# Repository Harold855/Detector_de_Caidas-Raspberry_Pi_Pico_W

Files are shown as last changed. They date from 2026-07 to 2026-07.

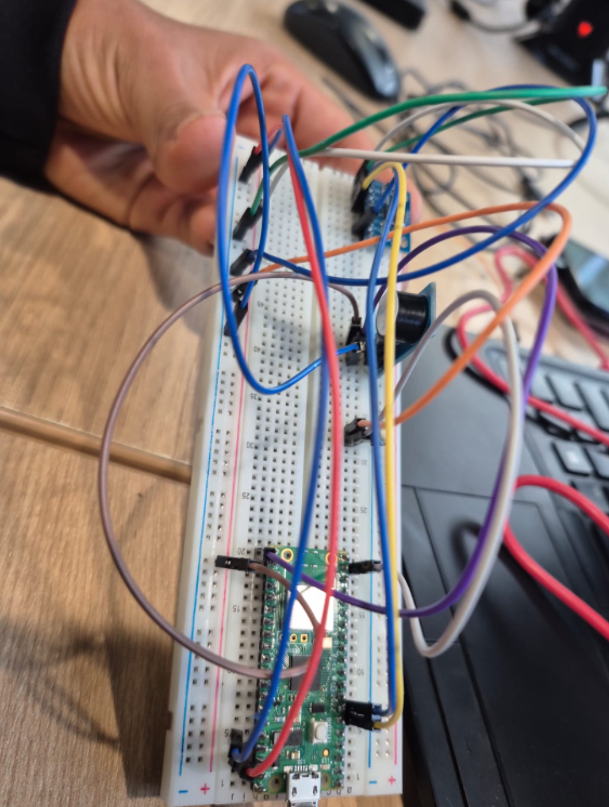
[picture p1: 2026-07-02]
evidencias/Avance Presencial/Evidencia_Avance_2.png

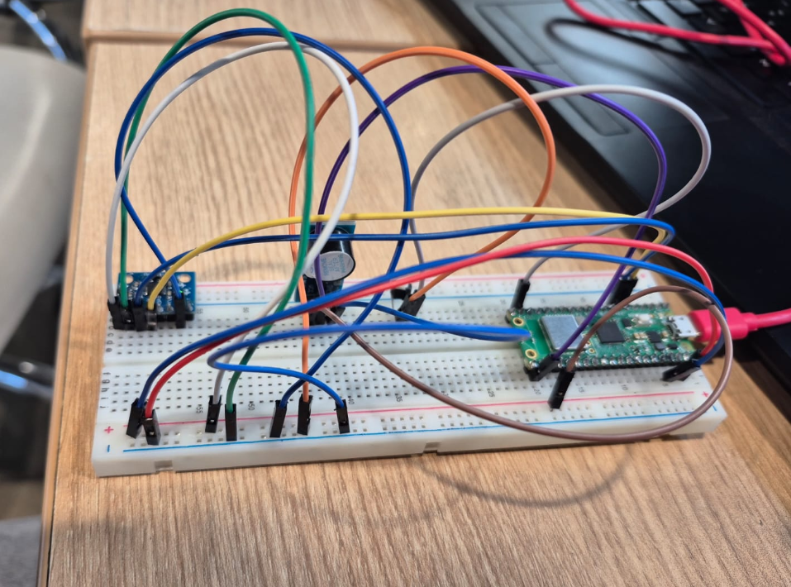
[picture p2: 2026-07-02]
evidencias/Avance Presencial/Evidencia_Avance_1.png

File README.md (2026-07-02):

# Sistema IoT de Detección de Caídas para Adultos Mayores

## Descripción

Este proyecto consiste en la implementación de un sistema con microcontrolador, codificado en MicroPython, en un dispositivo portátil. Este sistema usa una Raspberry Pi Pico W, un sensor MPU6050, ,un buzzer, un botón de cancelación y un bot de Telegram para enviar alertas a un grupo familiar.

## Razón de Creación o Problema Principal

Las caídas en adultos mayores pueden ocurrir cuando la persona se encuentra sola o sin supervisión. Y en algunos casos, la persona puede tener dificultad para levantarse o incluso pueden quedar incapaces de pedir ayuda. Por ello, este sistema busca alertar rápidamente, mediante un mensaje a los familiares en un grupo de Telegram, cuando se detecta un movimiento brusco relacionado con una posible caída.

## Usuario objetivo

El sistema está dirigido principalmente a adultos mayores que normalmente permanecen solos en casa. También beneficia a familiares o cuidadores, ya que les permite recibir alertas mediante Telegram.

## Componentes usados

|**Componente**|**Función**|
|-|-|
|Microcontrolador Raspberry Pi Pico W|Controla el sistema y se conecta a interne|
|Módulo IMU MPU6050|Detecta aceleración, giro e inclinación |
|Buzzer/Zumbador|Emite la alarma sonora|
|Botón pulsador|Cancela falsas alarmas o silencia la alarma|
|Powerbank|Alimenta el sistema|
|Carcasa impresa en 3D|Protege los componentes y permite colocarlo en una correa|

## Funcionamiento

El sistema lee constantemente los valores del MPU6050. La detección no se basa solo con un golpe o movimiento brusco. Primero, el sistema revisa si hubo un giro fuerte acompañado de movimiento. Luego, durante unos segundos, verifica si la persona quedó en una postura anormal y con poca movilidad.
Si estas condiciones se cumplen, el sistema interpreta que puede tratarse de una posible caída. En ese momento, el buzzer emite una alarma y el bot de Telegram envía un mensaje de posible caída al grupo familiar.
Después, el sistema espera 5 segundos para que la persona pueda cancelar la alerta con un toque en el botón. Si presiona el botón, se envía un mensaje de falsa alarma. Si no lo presiona, el sistema confirma la emergencia y envía un mensaje urgente al grupo familiar.
Además, el programa revisa periódicamente la conexión Wi-Fi. Si se desconecta, intenta reconectarse. También incluye un pequeño pulso del buzzer para evitar que algunos powerbanks se apaguen automáticamente por bajo consumo.

## Mensajes de Telegram

El bot puede enviar los siguientes mensajes:

* Dispositivo conectado y listo
* Posible caída detectada
* Falsa alarma cancelada
* Caída confirmada
* Alarma silenciada

## Cómo puedes ejecutar el proyecto

Si deseas ejecutar el proyecto por tu cuenta, debes seguir estos 7 pasos:

1. Instalar MicroPython en la Raspberry Pi Pico W
2. Abrir Thonny
3. Copiar el código en la Pico W
4. Guardar el archivo como "main.py"
5. Conectar el circuito según el diagrama
6. Conectar la Pico W a una laptop o powerbank
7. Verificar que el bot envíe mensajes al grupo de Telegram

## Seguridad de credenciales

Por seguridad, no se deben subir al repositorio los datos reales de Wi-Fi ni el token del bot de Telegram. Por lo que, el archivo con los datos reales solo debe usarse en la Raspberry Pi Pico W.

WIFI_NOMBRE = "COLOCA AQUI EL NOMBRE DE TU WIFI"
WIFI_CLAVE = "COLOCA AQUI LA CLAVE TU WIFI"
TELEGRAM_TOKEN = "COLOCA AQUI EL TOKEN GENERADO POR TU BOT"
TELEGRAM_CHAT_ID = "COLOCA AQUI TU ID DEL CHAT"

## Diagrama de conexiones

|Componente|Pin en Raspberry Pi Pico W|
|-|-|
|MPU6050 SDA|GP4|
|MPU6050 SCL|GP5|
|MPU6050 VCC|3V3|
|MPU6050 GND|GND|
|Botón Pulsador|GP14 y GND|
|Buzzer|GP16, 3V3 y GND|
|Powerbank|Puerto Micro USB de la Pi Pico W|

## Diagrama de flujo del sistema

```mermaid
flowchart TD 
   A[Inicio] --> B[Conectar Wi-Fi]
   B --> C[Leer sensor MPU6050]
   C --> D{¿Detecta posible caída?}
   
   D -- No --> C
   D -- Sí --> E[Activar buzzer]
   E --> F[Enviar aviso a Telegram]
   F --> G{¿Presionó el botón en 5 segundos?}

   G -- Sí --> H[Cancelar alerta]
   H --> I[Enviar falsa alarma a Telegram]
   I --> C

   G -- No --> J[Confirmar emergencia]
   J --> K[Enviar caída confirmada a Telegram]
   K --> L[Sonar alarma]
   L --> M{¿Alguien silencia la alarma?}
   
   M -- Sí --> N[Enviar alarma silenciada]
   N --> C

   M -- No --> L

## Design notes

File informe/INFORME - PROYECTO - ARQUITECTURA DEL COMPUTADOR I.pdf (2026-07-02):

FACULTAD DE INGENIERÍA

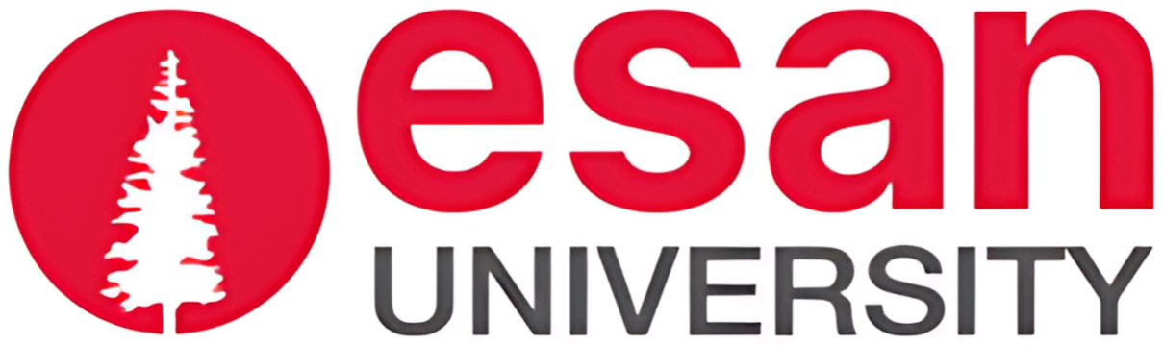
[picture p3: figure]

PROYECTO FINAL - GRUPO 6

Detección de Caídas para Adultos Mayores

CURSO: ARQUITECTURA DEL COMPUTADOR I

SECCIÓN: 001

PROFESOR: MARKS CALDERÓN

INTEGRANTES:

- Jorge Daniel Rivera Nagaro | 23101246
- Rodrigo Sebastián Escobar Rosado | 25100454
- Harold Lincoln Payco Espinoza | 25102426

Lima 2026

Índice

Introducción

Problema Real

Las caídas en adultos mayores son situaciones que pueden ocurrir en cualquier momento,

especialmente cuando la persona se encuentra sola en casa o no cuenta con supervisión

constante. En muchos casos, después de una caída, la persona puede tener dificultad para

levantarse, pedir ayuda o comunicarse rápidamente con sus familiares. Además, esto puede

llegar a ser grave, debido a que una caída puede ocasionar lesiones importantes y poner en

riesgo la salud de la persona afectada . Por ello, es importante contar con una herramienta que

permita avisar de manera oportuna cuando ocurre un movimiento brusco que pueda estar

relacionado con una posible caída.

Usuario Principal

Como se mencionó anteriormente, este dispositivo está enfocado principalmente en adultos

mayores que permanecen solos durante algunas horas del día o que requieren mayor cuidado

por parte de sus familiares. También beneficia a los familiares o cuidadores, ya que les

permite recibir una alerta rápida en caso de que la persona pueda necesitar ayuda.

Objetivo del proyecto

El objetivo del proyecto es desarrollar un dispositivo portátil que pueda colocarse en la

cintura de una persona mayor para detectar movimientos bruscos o cambios repentinos de

posición. Cuando el sistema identifica una posible caída, activa una alarma sonora y envía un

aviso automático a un grupo familiar de Telegram. Además, permite cancelar la alerta

mediante un botón si la persona se encuentra bien.

Alcance del proyecto

El proyecto consiste en un prototipo académico de detección y aviso de posibles caídas. Con

este sistema no busca reemplazar la atención médica ni garantizar la detección exacta de

todas las caídas; más bien, sirve como una herramienta de apoyo para mejorar la

comunicación entre el adulto mayor y sus familiares. Su funcionamiento se basa en la lectura

del movimiento del cuerpo, la activación de una alarma local y el envío de mensajes de alerta

mediante conexión a internet.

Diseño del sistema

Arquitectura del sistema

El sistema fue diseñado como un dispositivo portátil que puede colocarse en la cintura de una

persona mayor. Su funcionamiento inicia cuando el sensor MPU6050 registra los

movimientos del cuerpo. Luego, la Raspberry Pi Pico W analiza esos datos para identificar si

hubo un giro brusco acompañado de movimiento fuerte.

A diferencia de una detección simple, el sistema no confirma una posible caída solo por un

golpe o movimiento repentino. Primero revisa si ocurrió un giro fuerte y luego, observa si,

durante unos segundos, la persona quedó quieta y en una postura anormal. Cuando estas

condiciones se cumplan, el sistema activa el buzzer y envía un aviso al grupo familiar de

Telegram. Además, el sistema permite cancelar la alerta mediante un botón. Si la persona

presiona el botón dentro del tiempo establecido, se informa que fue una falsa alarma. En

cambio, si no se presiona, el sistema confirma la emergencia y envía un mensaje urgente al

grupo familiar.

Componentes del sistema

El sistema está formado por una Raspberry Pi Pico W, un módulo MPU6050, un buzzer, un

botón pulsador, conexión Wi-Fi, un bot de Telegram, una batería recargable o powerbank,

una carcasa impresa en 3D y una correa ajustable. La Raspberry Pi Pico W controla el

funcionamiento del sistema y permite la conexión a internet. El MPU6050 mide la

aceleración, el giro y la inclinación del cuerpo. El buzzer funciona como alarma sonora local.

El botón permite cancelar una falsa alarma o silenciar la emergencia cuando alguien ya se

encuentra con la persona. Finalmente, Telegram permite enviar los mensajes al grupo

familiar.

Funcionamiento de los dos sensores del MPU6050

El módulo MPU6050 integra dos mediciones principales, estas serían: la aceleración y giro.

La aceleración permite identificar movimientos bruscos o golpes, por ejemplo, cuando el

cuerpo cambia de posición de manera repentina. Por otro lado, el giro permite reconocer

rotaciones rápidas o inclinaciones que podrían ocurrir durante una caída. Aparte este tiene un

papel importante, ya que se utiliza como primer filtro para detectar un evento que podría estar

relacionado con una caída. Después de ello, el sistema revisa si la persona quedó en una

posición anormal y con poca movilidad. De esta manera, el dispositivo no depende de un solo

dato, sino que combina movimiento, giro, postura y quietud.

Lógica de detección

La lógica de detección se divide en dos momentos. Primero, el sistema revisa si hubo un giro

brusco acompañado de movimiento. Si no ocurre este evento, el dispositivo continúa leyendo

los datos del sensor sin activar ninguna alerta.

Si el giro brusco sí ocurre, el sistema realiza una segunda verificación. Revisa, durante unos

segundos, si la persona quedó en una postura anormal y con poca movilidad. Si estas

condiciones no se llegan a cumplir, el sistema descarta el evento porque puede tratarse de un

movimiento normal, como girarse rápido, sentarse o mover el dispositivo.

En cambio, si el sistema detecta giro brusco, postura anormal e inmovilidad, se activa el

buzzer y se envía un mensaje de posible caída a Telegram. Luego, la persona tiene 5

segundos para cancelar la alerta con un toque en el botón. Si presiona el botón, se informa

una falsa alarma. Si no lo presiona, el sistema confirma la emergencia y envía un mensaje

urgente al grupo familiar.

Implementación

Conexiones del circuito

Para la construcción del prototipo se utilizó una Raspberry Pi Pico W como unidad principal

del sistema. A esta placa se conectó el módulo MPU6050, encargado de medir los

movimientos del cuerpo. También se conectó un buzzer, que funciona como alarma sonora, y

un botón pulsador, que permite cancelar una falsa alarma o silenciar la alerta cuando alguien

ya se encuentra con la persona.

El MPU6050 se conectó a los pines GP4 y GP5 de la Raspberry Pi Pico W. El botón fue

conectado al pin GP14 y el buzzer al pin GP16. Y para la alimentación, se uso de una batería

recargable o powerbank mediante el puerto micro USB de la placa.

Programación en MicroPython

El código se organizó en varias funciones para facilitar su funcionamiento y explicación. Una

función prepara los componentes principales, la otra conecta el dispositivo al Wi-Fi, otra

envía mensajes a Telegram y otra lee los valores del sensor MPU6050.

Además, el programa incluye mejoras de estabilidad. Por ejemplo, revisando periódicamente

si la conexión Wi-Fi sigue activa y, si se pierde, intenta reconectarse. También realiza

reintentos al enviar mensajes por Telegram, para evitar que una falla momentánea de internet

detenga el aviso. También cuenta con un pequeño pulso del buzzer cada cierto tiempo. Esto

ayuda a evitar que algunos powerbanks se apaguen cuando detectan bajo consumo.

Finalmente, el programa cuenta con una protección que permite reiniciar la Raspberry Pi Pico

W si ocurre un error grave, de modo que el sistema pueda seguir funcionando mientras tenga

energía.

Flujo del programa

El programa inicia preparando el buzzer, el botón, el sensor MPU6050 y la conexión Wi-Fi.

Luego, si la conexión a internet está disponible, envía un mensaje inicial al grupo familiar de

Telegram indicando que el dispositivo está listo. Después, el sistema entra en un ciclo

continuo de lectura. En cada lectura, obtiene información sobre aceleración, giro e

inclinación. Si detecta un giro brusco acompañado de movimiento, no activa la alarma de

inmediato, sino que realiza una verificación adicional. En esta etapa se revisa si la persona

quedó en una postura anormal y con poca movilidad.

Si la verificación confirma una posible caída, el buzzer se activa y el sistema envía un

mensaje de posible caída a Telegram. Luego, la persona tiene 5 segundos para cancelar la

alerta mediante un toque en el botón. Si el botón es presionado, se envía un mensaje de falsa

alarma. Si no es presionado, se confirma la emergencia y se envía un mensaje urgente al

grupo familiar.

Alerta por Telegram

Para el envío de alertas se creó un bot de Telegram mediante BotFather. Este bot fue

agregado a un grupo familiar, donde se reciben los mensajes generados por el sistema.

El sistema puede enviar distintos mensajes según la situación. Primero, informa que el

dispositivo se conectó correctamente. Luego, si detecta una posible caída, envía un aviso de

alerta. Si la persona presiona el botón, se informa que fue una falsa alarma. Si la alerta no se

cancela, se envía un mensaje de caída confirmada. Finalmente, si alguien llega al lugar y

silencia la alarma, también se envía un aviso al grupo.

Además, se considera la reconexión a Wi-Fi. Por ello, si el dispositivo pierde conexión

durante una emergencia, intenta recuperarla para poder volver a enviar mensajes.

Resultados y Pruebas

Pruebas Realizadas

Para comprobar el funcionamiento del sistema, se realizaron diferentes pruebas con el prototipo

conectado a la Raspberry Pi Pico W. Estas pruebas permitieron verificar la lectura del sensor, el

sonido del buzzer, el uso del botón, la conexión Wi-Fi, el uso con powerbank y el envío de mensajes

al grupo familiar de Telegram .

Tabla 1

Pruebas realizadas al sistema de detección de caídas

Prueba Realizada | Resultado Esperado | Resultado Obtenido
Encendido del dispositivo | El sistema debe conectarse a la red Wi-Fi y enviar un mensaje inicial a Telegram | El dispositivo se conectó correctamente y envió el mensaje de inicio al grupo familiar
Dispositivo en reposo | No debe activarse la alarma | No se generó ninguna alerta mientras el dispositivo permaneció quieto
Movimiento suave | El sistema no debe considerar el movimiento como una caída | No se activó la alarma con movimientos leves
Giro brusco sin postura anormal | El sistema debe activar la alerta. | El sistema no confirmó caída cuando no hubo postura anormal ni quietud posterior
Giro brusco con postura anormal e inmovilidad | El sistema debe activar la alerta | El buzzer sonó y se envió un mensaje de posible caída a Telegram
Presionar el botón dentro de los 5 segundos | La alerta debe cancelarse como falsa alarma | El sistema apagó el buzzer y envió el mensaje de falsa alarma

No presionar el botón | El sistema debe confirmar la caída y enviar una alerta de emergencia | Se envió el mensaje de caída confirmada al grupo familiar
Silenciar la alarma con la secuencia de toques | El sistema debe apagar la alarma local | La alarma se silenció correctamente y se envió un aviso a Telegram
Desconexión temporal del Wi-Fi | El sistema debe intentar reconectarse | El sistema intentó recuperar la conexión y continuó funcionando
Uso con powerbank | El sistema debe funcionar sin estar conectado a la laptop | El dispositivo funcionó como prototipo portátil

Lecturas del sensor

Durante las pruebas, el sistema mostró valores de aceleración, giro e inclinación. Estos datos

permitieron observar la diferencia entre un movimiento normal y un evento que podría estar

relacionado con una caída.

Un ejemplo de lectura en reposo fue el siguiente:

- Aceleración: 1.02 g | Giro total: 5.84 °/s | Roll: 3.22° | Pitch: -1.45°

Un ejemplo de lectura durante un giro brusco fue el siguiente:

- Aceleración: 1.75 g | Giro total: 270 °/s | Roll: 58.40° | Pitch: 12.30°

Se concluye que el sistema no confirma una caída solo con estos valores iniciales. Después

del giro brusco, este también revisa si la persona quedó en una postura anormal y con poca

movilidad. Esto permite reducir falsas alarmas por movimientos fuertes que no representan

una caída real.

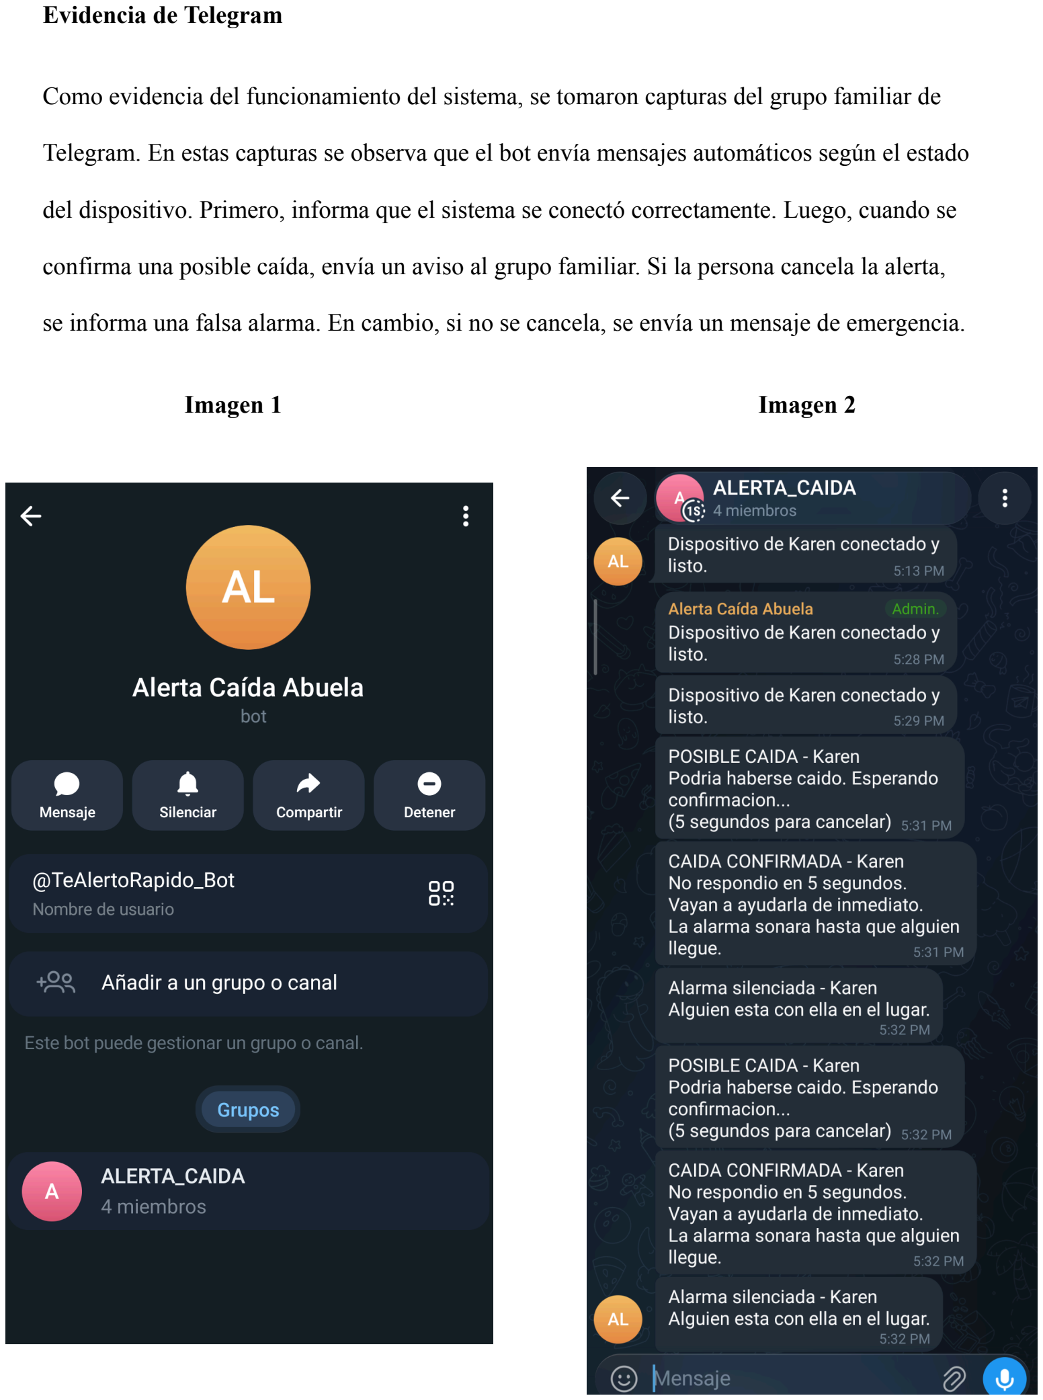
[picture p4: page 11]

Evidencia de Telegram

Como evidencia del funcionamiento del sistema, se tomaron capturas del grupo familiar de

Telegram. En estas capturas se observa que el bot envía mensajes automáticos según el estado

del dispositivo. Primero, informa que el sistema se conectó correctamente. Luego, cuando se

confirma una posible caída, envía un aviso al grupo familiar. Si la persona cancela la alerta,

se informa una falsa alarma. En cambio, si no se cancela, se envía un mensaje de emergencia.

Imagen 1 | Imagen 2

Limitaciones observadas

Durante las pruebas se identificaron algunas limitaciones. En primer lugar, el sistema

generaba falsas alarmas si el dispositivo se mueve de forma muy brusca o si no está bien

colocado en la cintura. Sin embargo, se corrigió este problema y ahora, el sistema está

preparado, pues con su verificación de postura e inmovilidad ayuda a reducir bastante este

problema.

En segundo lugar, el envío de mensajes por Telegram depende de la conexión a internet. Si la

red Wi-Fi no está disponible, el sistema puede seguir activando el buzzer, pero no podrá

enviar mensajes hasta recuperar la conexión.

Finalmente, el uso con powerbank puede presentar una dificultad adicional, ya que algunos

modelos se apagan cuando detectan bajo consumo. Para reducir este problema, el programa

incluye un pequeño pulso del buzzer cada cierto tiempo; sin embargo, su efectividad depende

del modelo de powerbank utilizado.

Carcasa 3D e Integración Física

Composición

La carcasa 3D se creo como una base de protección y soporte para los componentes

principales del sistema. En su interior se considera el espacio necesario para colocar la

Raspberry Pi Pico W, el sensor MPU6050, el buzzer, el botón pulsador y la batería

recargable. De esta manera, los elementos del circuito pueden mantenerse ordenados y

protegidos durante el uso del dispositivo. Además, la carcasa permite que el sensor

permanezca fijo, lo cual es importante para que las lecturas de movimiento sean más estables.

También cuenta con un espacio para el botón, de modo que la persona pueda presionarlo con

facilidad en caso de una falsa alarma. Asimismo, se considera una abertura para que el sonido

del buzzer pueda escucharse con claridad.

Medidas

El modelo de la carcasa fue elaborado en un archivo con formato STL, listo para impresión

3D. Según la revisión del modelo, sus medidas aproximadas son 310 mm de largo, 85.5 mm

de ancho y 52 mm de alto. Estas dimensiones permiten integrar los componentes del sistema

y considerar un espacio adicional para la batería recargable. Antes de realizar la impresión

final, se recomienda verificar la escala del archivo en el programa de impresión 3D, ya que el

formato STL puede abrirse en diferentes unidades según el software utilizado. Esto permite

asegurar que la carcasa tenga el tamaño adecuado para los componentes reales.

Integración con la correa

La carcasa está pensada para colocarse junto a una correa o cinturón ajustable. Esta correa

permitirá ubicar el dispositivo en la cintura de la persona mayor, siendo esta una posición

adecuada para detectar movimientos bruscos, giros o cambios repentinos de postura.

La correa no será impresa en 3D, ya que puede utilizarse una correa flexible y ajustable. Sin

embargo, la carcasa sí cumple la función de pieza impresa, debido a que sostiene y protege el

sistema electrónico. Con esta integración, el prototipo deja de ser solo un circuito de prueba y

se convierte en un dispositivo portátil que puede usarse de forma más realista durante la

demostración.

Imagen 3

Referencia del diseño 3D de la carcasa + correa

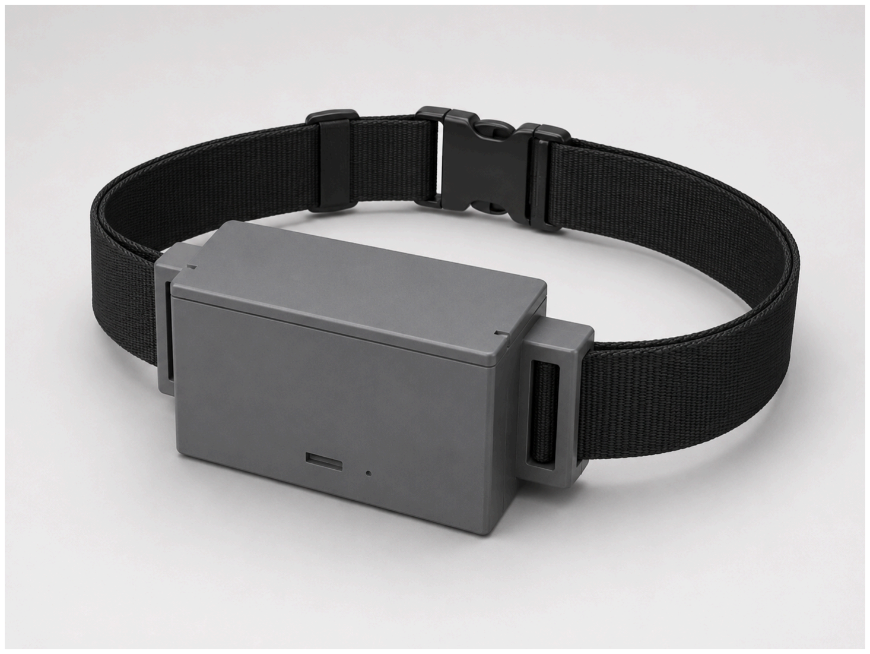
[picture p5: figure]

Nota: Diseño de imagen de referencia generada por IA por OpenAI, ChatGPT GPT - 5.5,

2026 (https://chatgpt.com/)

Conclusiones

Este proyecto permitió desarrollar un prototipo de detección de posibles caídas para adultos

mayores, utilizando una Raspberry Pi Pico W, un sensor MPU6050, un buzzer, un botón de

cancelación, una batería recargable y el envío de alertas mediante Telegram. También, el

sistema no solo detecta movimientos bruscos, sino que también verifica giro, postura anormal

e inmovilidad posterior, lo cual permite reducir falsas alarmas.

Asimismo, el trabajo permitió comprender mejor cómo funciona un microcontrolador y cómo

puede programarse para realizar diferentes tareas. Durante el curso se trabajaron ejercicios

más simples, como el control de luces LED, y este proyecto permitió aplicar esos

conocimientos en un sistema más completo y cercano a un problema real.

Como equipo, la experiencia también fue positiva, ya que permitió aprender sobre conexiones

electrónicas, lectura de sensores, programación en Micro Python y comunicación por internet.

Además, el proyecto ayudó también a comprender la importancia de probar cada parte por

separado antes de unir todo el sistema.

Sin embargo, también se presentaron algunas dificultades. Al inicio, el equipo no tenía una

idea clara de cómo empezar el proyecto ni cómo organizar las conexiones del circuito.

Además, surgieron problemas relacionados con el código, la impresión de la carcasa y la

elección de la fuente de alimentación. En un primer momento se evaluó el uso de pilas, pero

finalmente se optó por una batería recargable o powerbank debido a su mayor practicidad

para el uso del dispositivo.

Finalmente, pese a las dificultades, el equipo logró organizarse, distribuir tareas y completar

el funcionamiento principal del sistema. Se consiguió que el sensor detecte movimientos

bruscos, que el buzzer emita la alarma, que el botón permita cancelar o silenciar la alerta, y

que los mensajes lleguen correctamente al grupo familiar de Telegram. Además, se

incorporaron mejoras como la reconexión automática a Wi-Fi, el reintento de mensajes por

Telegram y un mecanismo para ayudar a mantener activo el powerbank. Estas mejoras

permitieron que el prototipo sea más estable y adecuado para una demostración autónoma. Y

que el sistema sea completamente transportable mediante una carcasa impresa 3D y una

correa.

Referencias

MicroPython. (s. f.). MicroPython documentation. https://docs.micropython.org/

Raspberry Pi Ltd. (s. f.). MicroPython on Raspberry Pi Pico. Raspberry Pi Documentation.

https://www.raspberrypi.com/documentation/microcontrollers/micropython.html

Raspberry Pi Ltd. (s. f.). Raspberry Pi Pico W datasheet: An RP2040-based microcontroller

board. https://pip.raspberrypi.com/documents/RP-008312-DS-pico-w-datasheet.pdf

Raspberry Pi Ltd. (s. f.). Raspberry Pi Pico-series documentation. Raspberry Pi

Documentation.

https://www.raspberrypi.com/documentation/microcontrollers/raspberry-pi-pico.html

TDK InvenSense. (2013). MPU-6000 and MPU-6050 product specification.

https://invensense.tdk.com/wp-content/uploads/2015/02/MPU-6000-Datasheet1.pdf

Telegram. (s. f.). Telegram Bot API. https://core.telegram.org/bots/api

World Health Organization. (2021, April 26). Falls.

https://www.who.int/news-room/fact-sheets/detail/falls

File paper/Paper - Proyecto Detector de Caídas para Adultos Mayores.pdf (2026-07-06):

# Implementación de un Sistema IoT para la Detección de Caídas en Adultos Mayores

Rivera Nagaro Jorge Daniel, Escobar Rosado Rodrigo Sebastián, Payco Espinoza Harold Lincoln Arquitectura del Computador I (Ciclo 2026-I) — Prof. Marks Calderón Niquin Universidad ESAN - Facultad de Ingeniería Lima, Perú – 2026

Resumen— Las caídas son una de las principales causas de lesión y pérdida de independencia en adultos mayores, y la falta de aviso oportuno agrava sus consecuencias. Este trabajo presenta el diseño e implementación de un dispositivo portátil de bajo costo, dirigido a adultos mayores que viven solos o con supervisión parcial, que detecta caídas mediante un sensor MPU6050 conectado a una Raspberry Pi Pico W y notifica automáticamente a un grupo familiar por Telegram. El sistema combina aceleración, giro, postura anormal e inmovilidad posterior para identificar una posible caída. Los resultados obtenidos muestran una tasa de acierto general de 81.08%, una latencia promedio de 2.53 s y un consumo energético entre 0.51 W y 0.86 W.

Palabras clave— adulto mayor, detección de caídas, IoT, MPU6050, Raspberry Pi Pico W, Telegram, dispositivo portátil.

Abstract— Falls are one of the leading causes of injury and loss of independence among older adults, and the lack of timely notification often worsens their consequences. This work presents the design and implementation of a low-cost wearable device aimed at older adults who live alone or with partial supervision. The system detects possible falls using an MPU6050 sensor connected to a Raspberry Pi Pico W and automatically notifies a family group via Telegram. It combines acceleration, rotation, abnormal posture, and subsequent immobility to identify a possible fall. The obtained results show an overall accuracy of 81.08%, an average alert latency of 2.53 s, and energy consumption between 0.51 W and 0.86 W.

Index Terms— older adult, fall detection, IoT, MPU6050, Raspberry Pi Pico W, Telegram, wearable device.

I. INTRODUCCIÓN

Las caídas en adultos mayores representan un problema importante, especialmente cuando la persona se encuentra sola en casa o no cuenta con supervisión constante. De acuerdo con la Organización Mundial de la Salud, las caídas son la segunda causa mundial de muerte por lesiones no intencionales, después de los accidentes de tránsito [1]. Esta situación puede ser más grave en personas mayores, ya que una caída puede ocasionar lesiones, dificultad para levantarse o imposibilidad de pedir ayuda a tiempo.
En este contexto, el problema que aborda el proyecto es la falta de un aviso rápido cuando un adulto mayor sufre una posible caída en el hogar. Por ello, se propone un dispositivo portátil que pueda detectar movimientos relacionados con una caída y enviar una alerta automática a sus familiares.
El sistema está dirigido principalmente a adultos mayores que permanecen solos durante algunas horas del día o que requieren mayor acompañamiento por parte de sus familiares. También está orientado a los familiares o cuidadores, quienes reciben la alerta en un grupo de Telegram y pueden actuar con mayor rapidez ante una posible emergencia.
El dispositivo se plantea para un uso doméstico y portátil, colocado en la cintura mediante una correa ajustable. Esta ubicación permite que el sensor registre movimientos del cuerpo, giros e inclinaciones durante el desplazamiento normal de la persona. Además, se buscó que el dispositivo sea económico, reproducible con componentes de bajo costo y fácil de replicar en un contexto académico.
La motivación principal del proyecto es crear una herramienta accesible que ayude a reducir el tiempo de aviso ante una posible caída. Existen sistemas comerciales de monitoreo, pero no siempre son económicos o fáciles de adaptar a un proyecto académico. Por esta razón, se eligieron componentes de bajo costo y disponibles, como la Raspberry Pi Pico W y el sensor MPU6050.

II. ESTADO DEL ARTE
A. Importancia de la detección de caídas
Las caídas en adultos mayores son un problema ampliamente estudiado debido a sus consecuencias físicas y sociales. La Organización Mundial de la Salud señala que las caídas son la segunda causa mundial de muerte por lesiones no intencionales y que cada año se producen aproximadamente 684000 muertes por esta causa [1]. Por ello, en los últimos años se han desarrollado diferentes sistemas para detectar caídas y reducir el tiempo de respuesta ante una emergencia. Mubashir et al. clasifican los sistemas de detección de caídas en tres grupos principales: sistemas basados en dispositivos portátiles, sistemas basados en sensores ambientales y sistemas basados en visión [2]. Los sistemas basados en visión pueden ofrecer buenos resultados, pero requieren cámaras y pueden generar problemas de privacidad. Los sistemas ambientales, como sensores de presión o radar, dependen de la infraestructura instalada en el entorno. En cambio, los dispositivos portátiles permiten que la persona lleve el sistema consigo, lo que resulta más adecuado para un prototipo de bajo costo y uso doméstico.

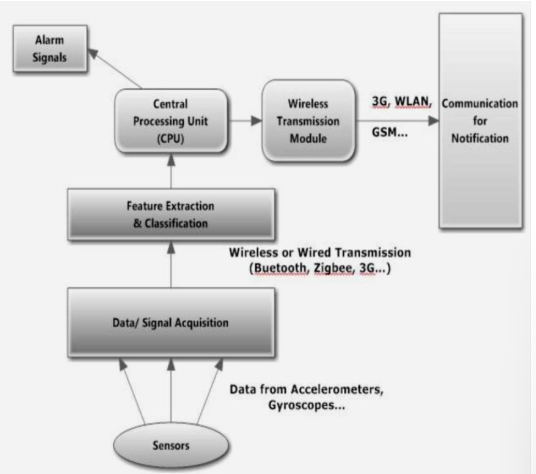
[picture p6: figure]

Figura 1. Diagrama de bloques basado en las revisiones de Mubashir et al. sobre sistemas de detección de caídas.

B. Dispositivos portátiles con sensores inerciales
Los dispositivos portátiles suelen utilizar sensores inerciales, como acelerómetros y giroscopios, para medir el movimiento del cuerpo. Subramaniam et al. señalan que las unidades de medición inercial son comunes en sistemas portátiles porque permiten registrar aceleración, orientación y características del movimiento corporal [3]. De manera similar, Chen et al. revisaron tecnologías portátiles para evaluación del riesgo de caídas y encontraron que 25 estudios fueron seleccionados de 614 artículos iniciales, lo que muestra que existe una línea de investigación activa en este tipo de soluciones [4].

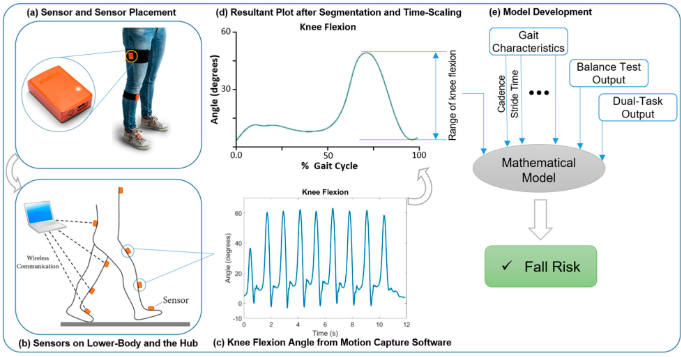
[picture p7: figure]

Figura 2. Ejemplo de método de estudio basado en sensores portátiles para evaluación de riesgo de caída.

C. Algoritmos de detección
En la literatura existen dos enfoques comunes para detectar caídas: los algoritmos basados en umbrales y los algoritmos basados en aprendizaje automático. Los algoritmos basados en umbrales comparan los valores del sensor con límites definidos previamente. Su principal ventaja es que son simples, rápidos y adecuados para microcontroladores de bajo consumo. Sin embargo, pueden generar falsas alarmas si solo consideran un movimiento fuerte o un golpe aislado.
Ramachandran y Karuppiah revisaron avances recientes en sistemas portátiles de detección de caídas. Dentro de los estudios revisados, Li et al. propusieron un algoritmo de tres pasos basado en intensidad de actividad, postura y transición, usando acelerómetros y giroscopios, con una sensibilidad de 91% y una especificidad de 92% para distinguir caídas de actividades normales o similares a caídas [5].

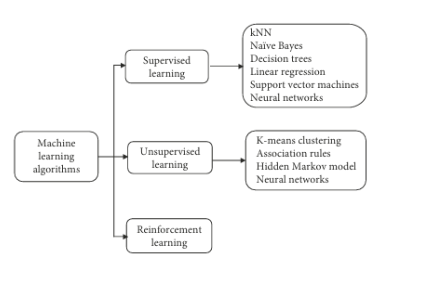
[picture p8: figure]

Figura 3. Taxonomía de algoritmos de aprendizaje automático aplicados a detección de caídas.

Los métodos basados en aprendizaje automático pueden mejorar la clasificación entre caídas y movimientos normales, pero estos requieren más datos, mayor procesamiento y entrenamiento previo. Por ejemplo, CareFall compara enfoques basados en umbrales y aprendizaje automático utilizando señales de acelerómetro y giroscopio de relojes inteligentes, concluyendo que el aprendizaje automático puede superar al método por umbrales en precisión, sensibilidad y especificidad. [6].

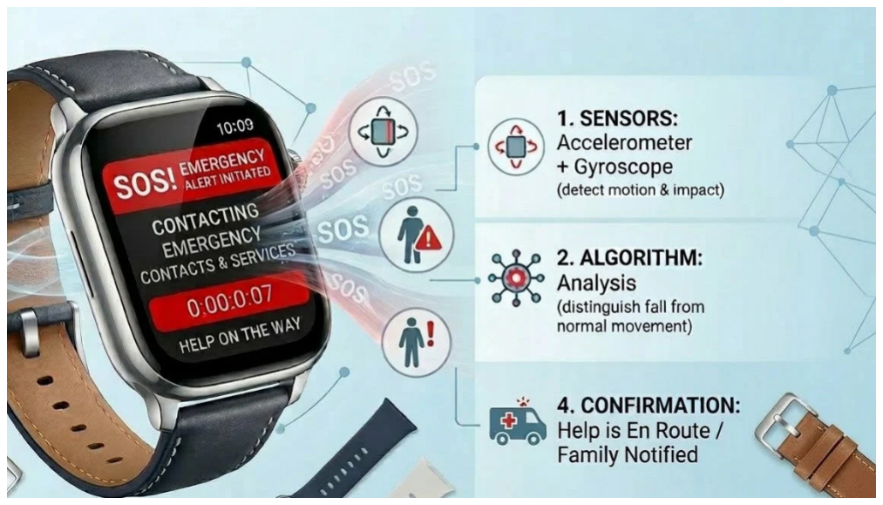
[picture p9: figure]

Figura 4. Sistema CareFall como ejemplo de solución con smartwatch, sensores inerciales y algoritmo de clasificación.

III. METODOLOGÍA

A. Enfoque metodológico del proyecto
El desarrollo del prototipo se dividió en seis etapas principales: planificación, selección de componentes, desarrollo del software, integración individual, integración total y pruebas finales. Esta secuencia permitió construir el sistema por partes y comprobar el funcionamiento de cada módulo antes de unirlo en un solo dispositivo. De esta manera, se redujo el riesgo de fallas durante la integración final.

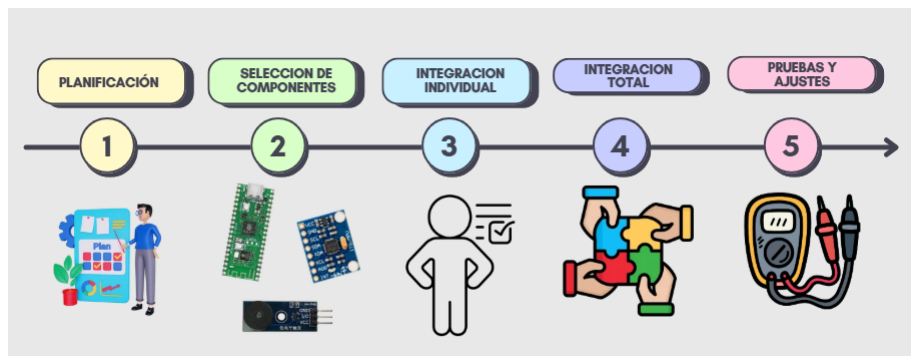
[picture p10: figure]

Figura 5. Proceso metodológico de desarrollo del prototipo.

B. Arquitectura general del sistema
La arquitectura del sistema se basa en la interacción entre el sensor de movimiento, la unidad de control, la alarma local y el sistema de notificación. El MPU6050 registra la aceleración, el giro y la inclinación del cuerpo. Luego, la Raspberry Pi Pico W procesa estos datos y determina si existe una posible caída. Si el evento es confirmado, el buzzer emite una alarma sonora y el bot de Telegram envía un mensaje al grupo familiar. Además, el botón pulsador permite cancelar una falsa alarma o silenciar el dispositivo cuando alguien ya se encuentra con la persona.

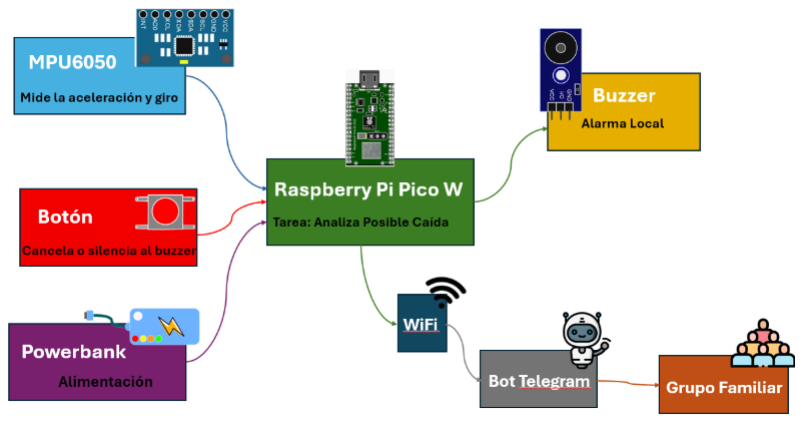
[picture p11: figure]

Figura 6. Arquitectura general del sistema propuesto.

C. Selección de componentes principales
La Raspberry Pi Pico W permite controlar sensores, manejar salidas como el buzzer y conectarse a internet mediante Wi-Fi. Según la documentación oficial de Raspberry Pi, esta placa integra conectividad inalámbrica de 2.4 GHz, lo que la hace adecuada para proyectos IoT de bajo costo. [7].

El sensor MPU6050 integra acelerómetro y giroscopio en un solo módulo. Esta característica permite medir movimientos bruscos, giros e inclinaciones del cuerpo. Además, el MPU6050 utiliza comunicación digital mediante I2C, lo que facilita su conexión con la Raspberry Pi Pico W [8].

Figura 7. Un dibujo deseñado en Draw.io sobre la Rasperry Pi Pico W

Figura 8. Un dibujo deseñado en Draw.io sobre el MPU6050

El buzzer se incorporó como alarma local. este es un pequeño transductor que convierte la energía eléctrica en sonido. Los tres pines corresponden a VCC (alimentación positiva, usualmente 5V), GND (tierra) y Señal. A diferencia de los modelos de dos pines, el tercer pin permite a tu placa controladora enviar instrucciones directas para emitir tonos específicos.

Figura 9. Un dibujo deseñado en Draw.io sobre el buzzer de 3 pines

El botón pulsador de 16 mm permite cancelar falsas alarmas o silenciar la emergencia. Este es un interruptor pequeño que abre o cierra un circuito eléctrico al presionarlo. Requiere un orificio de instalación de 16 milímetros (mm) y maneja hasta 220 voltios (V) de corriente.

Figura 10. Imagen del botón de 16mm, 5 pines, 12V-24V

Finalmente, el powerbank permite que el sistema funcione sin depender de una laptop, haciendo que el prototipo sea portátil.

D. Comunicación entre componentes
Como se puede observar en la Tabla I, para la comunicación entre la Raspberry Pi Pico W y el sensor MPU6050 se utilizó el protocolo I2C. Este protocolo emplea principalmente dos líneas de comunicación: SDA para datos y SCL para reloj. En el prototipo, SDA se conectó al pin GP4 y SCL al pin GP5. No se empleó SPI ni UART para el sensor porque I2C cubre la necesidad de lectura del MPU6050 con menos cables.

Tabla I
CONEXIONES PRINCIPALES DEL CIRCUITO
Componente | Conexión con Raspberry Pi Pico W
MPU6050 VCC | 3V3
MPU6050 GND | GND
MPU6050 SDA | GP4
MPU6050 SCL | GP5
Botón pulsador | GP14 y GND
Buzzer | GP16, VCC y GND
Powerbank | Puerto micro USB de la Pico W
E. Desarrollo del software en MicroPython

El firmware se implementó en MicroPython. La versión inicial usaba un bucle secuencial basado en time.sleep(), en el cual el envío de una notificación de Telegram (bloqueante, con reintento) podía congelar todo el programa hasta por 21 segundos, dejando de leer el sensor y de revisar el botón durante ese tiempo. Para corregir esto, el firmware se reescribió usando asyncio, ejecutando de forma concurrente tres tareas:
(1) detección de caídas, (2) monitoreo periódico de la conexión WiFi, y (3) un pulso anti-apagado para el power bank. El envío de mensajes a Telegram, por ser una llamada bloqueante de red incluso dentro de una tarea async, se delega al segundo núcleo del RP2040 mediante el módulo thread, encolando los mensajes para respetar la restricción de MicroPython de un solo hilo adicional activo a la vez. [9].
A diferencia de un cálculo de ángulo por ejes separados (roll/pitch), que presenta puntos ciegos según la dirección de la caída, el ángulo de postura se calcula mediante el producto punto entre la lectura actual del acelerómetro y un vector de referencia obtenido al calibrar (persona de pie, quieta), lo que hace que la detección sea independiente del ángulo exacto en que quedó montado el sensor dentro del cinturón. Si ambos criterios se cumplen, el sistema emite una notifi cación de “posible caída” y espera 5 segundos por un toque de cancelación. De no cancelarse, envía una notificación de “caída confirmada” y activa una alarma sonora continua, si lenciable únicamente mediante una secuencia de dos toques en una ventana de 2.2 segundos, o que se apaga automática mente tras 9 minutos si nadie responde.
F. Comunicación con Telegram

Para el envío de alertas se utilizó un bot de Telegram. El bot fue creado mediante BotFather y agregado a un grupo familiar. Cuando el sistema detecta una posible caída, la Raspberry Pi Pico W se conecta a internet y envía un mensaje al grupo mediante la API de Telegram. La versión final del programa incluye reintentos de envío y reconexión Wi-Fi para mejorar la estabilidad del aviso [10].

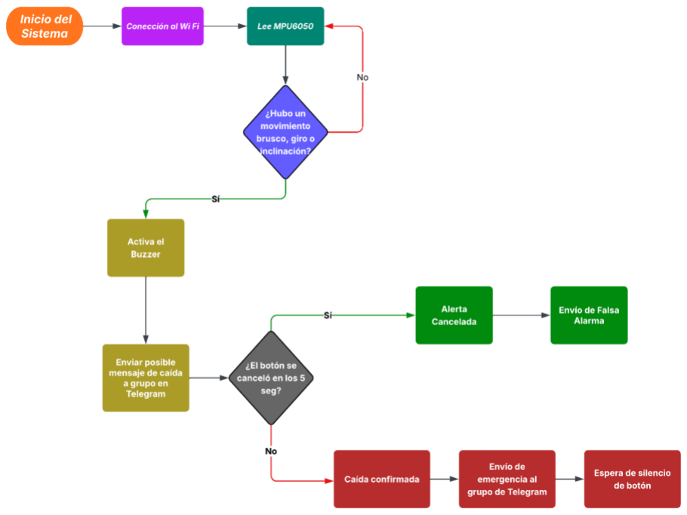
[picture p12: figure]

Figura 11. Diagrama de flujo del sistema de detección y alerta.

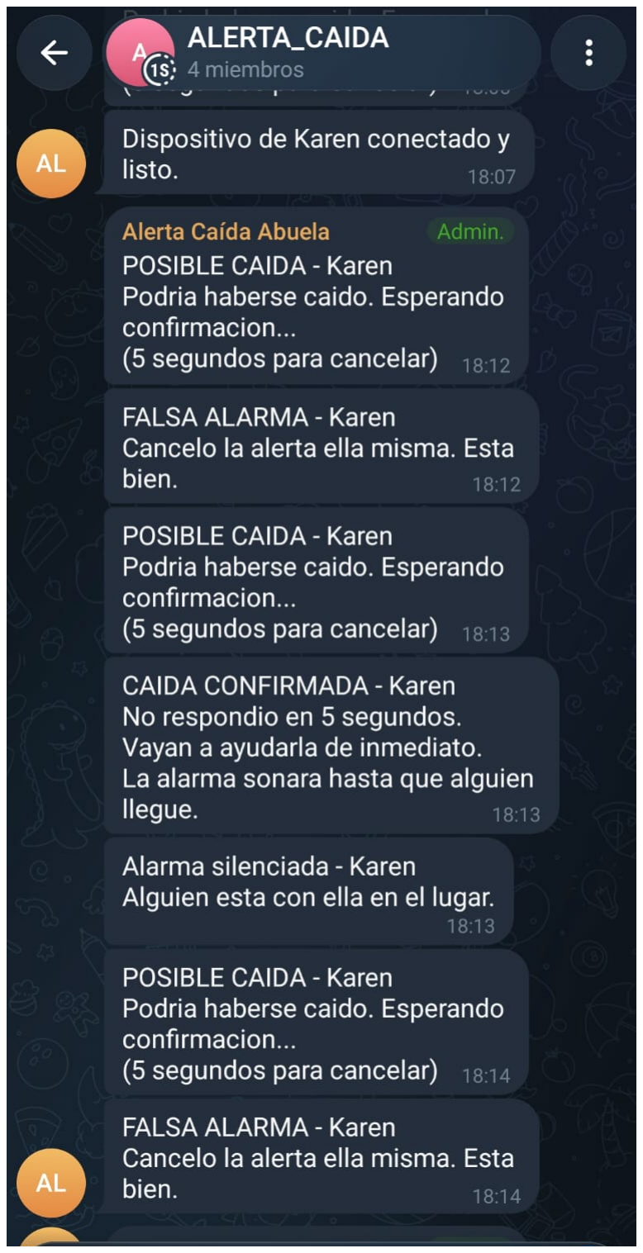
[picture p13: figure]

Figura 12. Evidencia del bot de Telegram y mensajes enviados al grupo familiar.

G. Nube

La comunicación con la nube se limita al envío de mensajes de texto mediante la API HTTP de Telegram "sendMessage" a un chat de grupo familiar identificado por su chat id, sin backend propio ni almacenamiento en servidores adicionales, lo que reduce la superficie de mantenimiento del sistema. La Figura 13 muestra evidencia real capturada durante las pruebas, con el ciclo completo de mensajes: confirmación de conexión del dispositivo, notificación de posible caída, cancelación exitosa dentro de la ventana de 5 segundos ("falsa alarma"), escalamiento a caída confirmada cuando no hay cancelación, y silenciamiento de la alarma una vez que alguien llega junto a la persona.

H. Pieza 3D

La carcasa se diseñó como una caja con tapa, con espacio interior para alojar la placa Pico W, el sensor MPU6050, el buzzer y la batería. Sus dimensiones exteriores medidas a partir del archivo STL son aproximadamente 192 × 169 × 83mm.

Figura 13. Modelo de carcasa 3D para integrar los componentes del sistema.

IV. RESULTADOS

A. Protocolo de pruebas

Para validar el funcionamiento del prototipo, se realizaron pruebas controladas con el dispositivo colocado en la cintura. Como se puede ver en la Tabla II, las pruebas se dividieron en actividades normales y eventos simulados de posible caída. En las actividades normales se consideró reposo, caminar, sentarse y movimientos suaves. En los eventos de posible caída se realizaron giros bruscos, inclinación anormal del dispositivo e inmovilidad posterior. Además, se evaluó el envío de mensajes por Telegram, el tiempo de llegada de la alerta, la cancelación mediante el botón y el funcionamiento con powerbank.

B. Precisión de detección

Como se puede observa en la Tabla III, el sistema obtuvo 30 aciertos en 37 pruebas realizadas, alcanzando un porcentaje general de acierto de 81.08 %. En actividades normales, el sistema evitó activar la alarma en 18 de 21 pruebas. En caídas simuladas, logró detectar correctamente 12 de 16 eventos.

C. Latencia de alerta

Se midió el tiempo transcurrido entre el instante de la caída simulada y la recepción del mensaje de Telegram en el dispositivo receptor, en 5 repeticiones con conexión WiFi estable. Como se puede observar en la Tabla IV, la latencia promedio fue de 2.53s, con un mínimo de 1.32s y un máximo de 3.53s. Estos tiempos indican que el sistema puede notificar una posible caída en pocos segundos siempre que exista conexión WiFi estable, aunque la latencia depende directamente de la disponibilidad de la red.

D. Consumo energético

Se midió el voltaje y la corriente de salida del powerbank en 5 estados de funcionamiento del prototipo. Como se puede observar en la Tabla V, el consumo varió entre 0.51W en reposo y 0.86W durante el envío de mensajes por Telegram, siendo la conexión WiFi la etapa de mayor demanda energética. Durante una emergencia completa (buzzer activo y notificación de red simultáneos), el consumo fue de aproximadamente 0.81W.

Tabla II
ESCENARIOS DE PRUEBA DEL SISTEMA
Escenario | Descripción | Resultado esperado
Reposo | Dispositivo quieto en
la cintura
No | debe | activar
alarma.

Caminata normal

Persona caminando
lentamente
No | debe | activar
alarma.
Sentarse | Persona | sentándose
normalmente
No | debe | activar
alarma.

Movimiento
suave

Movimiento
cotidiano del cuerpo
No | debe | activar
alarma.

Giro brusco sin
inmovilidad

Movimiento fuerte,
pero la persona sigue
activa
Debe | descartar | la
alerta.
Giro | brusco
+ | postura
anormal | +
quietud

Simulación de posible
caída

Debe activar buzzer y
Telegram.

Botón dentro
de 5 s

Cancelación de falsa
alarma
Debe | enviar | falsa
alarma.

No presionar
botón

Emergencia no cancelada

Debe | enviar | caída
confirmada.

Desconexión
Wi-Fi

Pérdida temporal de
internet
Debe | | intentar
reconectar.

Uso con powerbank

Funcionamiento sin
laptop

Debe mantenerse encendido.

Tabla III
RESULTADOS DE DETECCIÓN DEL SISTEMA
Tipo de prueba | N.º pruebas | Correctas | Acierto
Actividades normales | 21 | 18 | 85.71%
Caídas simuladas | 16 | 12 | 75.00%
Total | 37 | 30 | 81.08%

Tabla IV
MEDICIÓN DE LATENCIA DE ALERTA POR TELEGRAM
Prueba | Detección | Recepción | Latencia
1 | 00:12.30 | 00:15.50 | 3.20 s
2 | 00:15.25 | 00:18.78 | 3.53 s
3 | 00:11.98 | 00:14.05 | 2.07 s
4 | 00:11.92 | 00:13.24 | 1.32 s
5 | 00:12.48 | 00:15.03 | 2.55 s
Promedio | – | – | 2.53 s

Tabla V
MEDICIÓN DE CONSUMO ENERGÉTICO DEL SISTEMA
Estado del sistema | Voltaje | Corriente | Potencia
Reposo con Wi-Fi | 5.05 V | 0.10 A | 0.51 W
Lectura del MPU6050 | 5.05 V | 0.12 A | 0.61 W
Envío Telegram | 5.05 V | 0.17 A | 0.86 W
Buzzer activo | 5.05 V | 0.15 A | 0.76 W
Emergencia completa | 5.05 V | 0.16 A | 0.81 W
E. Análisis de resultados

En conjunto, los resultados muestran que el prototipo cumple su objetivo principal de detectar posibles caídas y notificar al grupo familiar mediante Telegram, con una tasa de acierto general de 81.08%. El mejor desempeño en actividades co tidianas (85.71%) frente a caídas simuladas (75.00%) sugiere que el criterio actual de umbral combinado (aceleración, giro y postura) es más efectivo evitando falsas alarmas que de tectando todas las variantes posibles de caída, lo cual es con sistente con la limitación conocida de los métodos basados en umbral frente a la variabilidad real de un evento de caída [5]. La latencia promedio de 2.53s confirma que la arquitectura basada en asyncio y en el segundo núcleo del RP2040 permite notificar de forma ráp ida sin bloquear la detección. Finalmente, el consumo medido (0.51–0.86W) indica que la etapa de comunicación WiFi es la de mayor impacto energético, información relevante para futuras estimaciones de autonomía del dispositivo.

V. CONCLUSIONES

Se diseñó e implementó un prototipo de detector de caídas de bajo costo que combina un criterio de umbral de aceleración/giro con verificación de postura calibrada por vector de referencia, y que notifica a un grupo familiar por Telegram sin bloquear la detección gracias al uso de asyncio y de un segundo núcleo dedicado al envío de red. Las pruebas realizadas muestran una precisión general de 81.08%, una latencia promedio de notificación de 2.53 segundos, y un consumo energético de entre 0.51W y 0.86W según el estado del sistema.
Entre las limitaciones identificadas se encuentran: (a) la posibilidad de que un reinicio inesperado del dispositivo mientras la persona está caída provoque una recalibración incorrecta del vector de referencia de postura; (b) la ventana de cancelación puede extenderse ligeramente más allá de los 5 segundos configurados debido a la granularidad del bucle de espera; (c) el sistema no puede distinguir, por diseño, entre una caída real y que la persona se acueste voluntariamente de forma que reproduzca el mismo patrón de quietud y postura anormal — esto se mitiga, no se resuelve, con la ventana de cancelación; (d) la tasa de detección en caídas simuladas (75.00%) aún deja margen de mejora frente a la de actividades cotidianas; y (e) el consumo energético se midió con el prototipo conectado directamente a la salida del powerbank, ya que este presentó apagado automático por bajo consumo en algunas pruebas preliminares, lo cual se identifica como una consideración práctica relevante para el diseño de la fuente de alimentación final.
Como trabajo futuro se plantea ampliar la cantidad de pruebas de precisión con mayor diversidad de usuarios y direcciones de caída, ajustar los umbrales de detección para mejorar la tasa de acierto en caídas simuladas, evaluar el comportamiento del dispositivo ante distintas posiciones de montaje del cinturón, y explorar el uso del sistema de interrupciones del propio MPU6050 para reducir el consumo en reposo frente al muestreo continuo actual.

Nota: Declaración de uso de IA. Durante la preparación de este trabajo, los autores utilizaron un asistente de inteligencia artificial (Claude, Anthropic) como apoyo en la redacción y corrección de estilo del texto, y en el procesamiento de las imágenes del prototipo y las capturas de evidencia utilizadas en las figuras del documento. Los autores revisaron, validaron y son responsables del con tenido técnico, los datos y las conclusiones finales de este trabajo .

REFERENCES

[1] World Health Organization, “Falls,” https://www.who.int/news-room/fact-sheets/detail/falls, (https://www.who.int/news-room/fact-sheets/detail/falls) Apr. 2021, accessed: 2026-07-05.
[2] M. Mubashir, L. Shao, and L. Seed, “A survey on fall detection: Principles and approaches,” Neurocomputing, vol. 100, pp. 144–152, 2013.
[3] S. Subramaniam, A. I. Faisal, and M. J. Deen, “Wearable sensor systems for fall risk assessment: A review,” Frontiers in Digital Health, vol. 4,
p. 921506, 2022.
[4] M. Abdollahi, E. Rashedi, S. Jahangiri, P. M. Kuber, N. Azadeh-Fard, and M. Dombovy, “Fall risk assessment in stroke survivors: A machine learning model using detailed motion data from common clinical tests and motor-cognitive dual-tasking,” Sensors, vol. 24, no. 3, p. 812, 2024.
[5] A. Ramachandran and A. Karuppiah, “A survey on recent advances in wearable fall detection systems,” BioMed Research International, vol. 2020, pp. 1–17, 2020.
[6] J. C. Ruiz-Garcia, R. Tolosana, R. Vera-Rodriguez, and C. Moro, “Carefall: Automatic fall detection through wearable devices and ai methods,” in CEUR Workshop Proceedings, vol. 3517, 2023, pp. 1–7.
[7] Raspberry Pi Ltd., Raspberry Pi Pico W Datasheet: An RP2040-based microcontroller board, https://pip.raspberrypi.com/documents/RP-008312-DS-pico-w-datasheet.pdf, (https://pip.raspberrypi.com/documents/RP-008312-DS-pico-w-datasheet.pdf) 2022, accessed: 2026-07-05.
[8] TDK InvenSense, MPU-6000 and MPU-6050 Register Map and Descriptions, https://cdn.sparkfun.com/datasheets/Sensors/Accelerometers/RM-MPU-6000A.pdf, (https://cdn.sparkfun.com/datasheets/Sensors/Accelerometers/RM-MPU-6000A.pdf) 2011, accessed: 2026-07-05.
[9] Raspberry Pi Ltd., “Micropython on raspberry pi pico,” https://www.raspberrypi.com/documentation/microcontrollers/micropython.html, 2026, accessed: 2026-07-05.
[10] Telegram, “Telegram bot api,” https://core.telegram.org/bots/api, 2026, accessed: 2026-07-05.

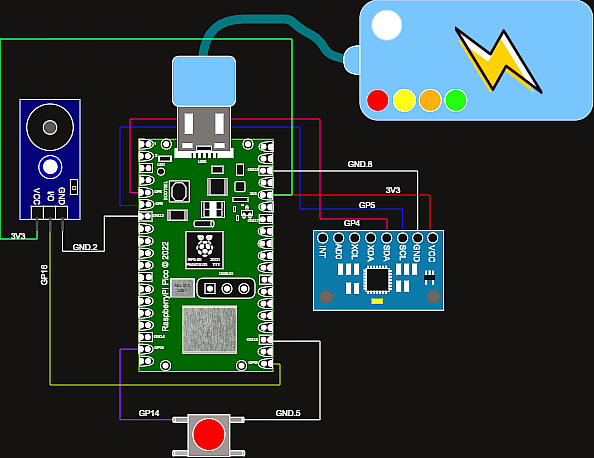
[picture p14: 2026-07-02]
diagramas/Diagrama de conexiones.png

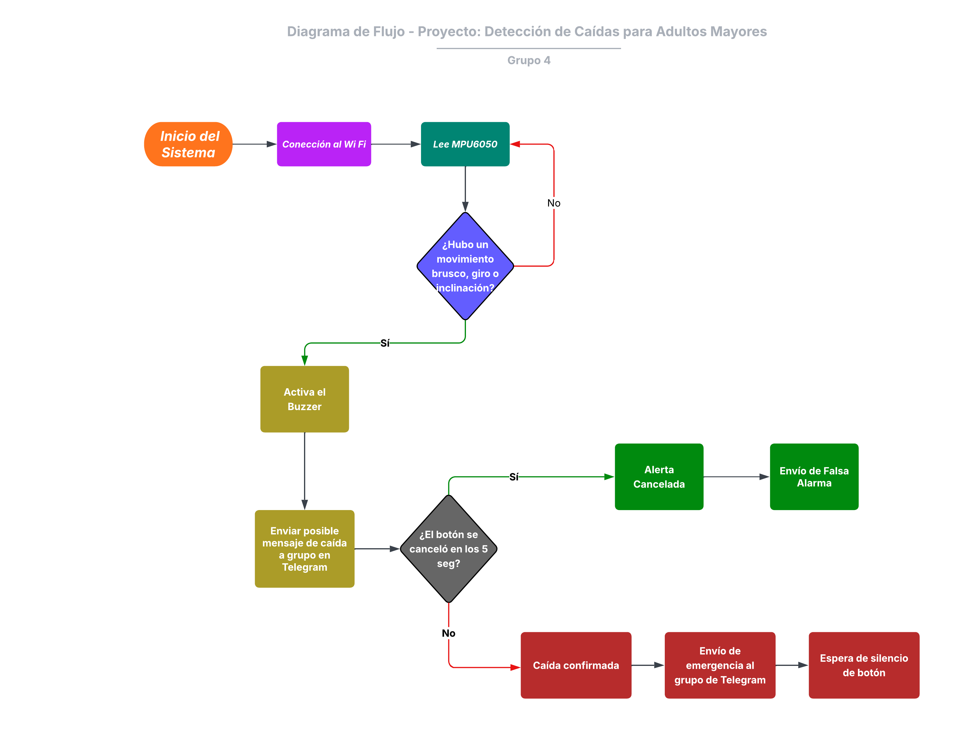
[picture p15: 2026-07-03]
diagramas/Diagrama de flujo.png

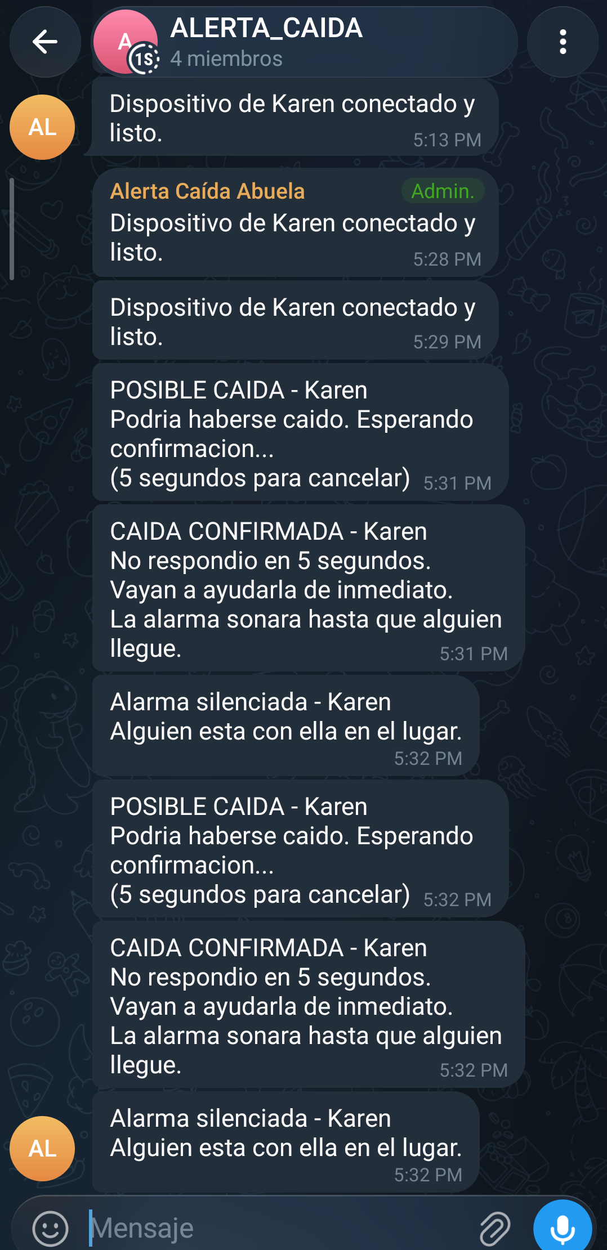
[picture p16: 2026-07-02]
evidencias/Telegram/Evidencia_Telegram_1.png

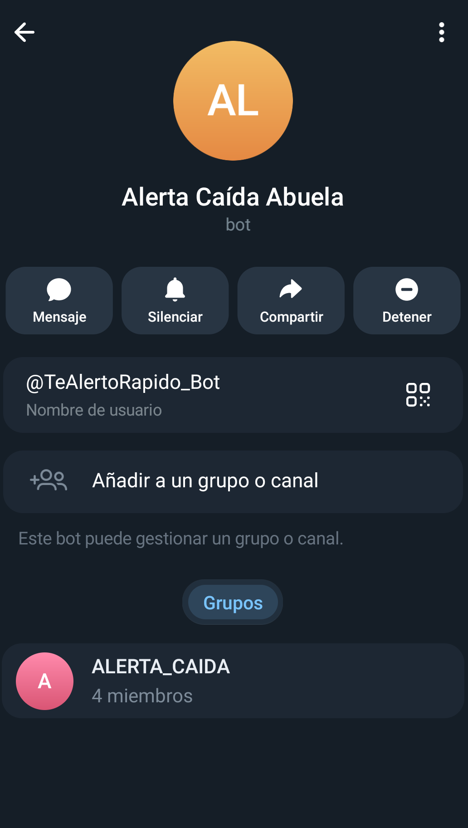
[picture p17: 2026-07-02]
evidencias/Telegram/Evidencia_Telegram_0.png

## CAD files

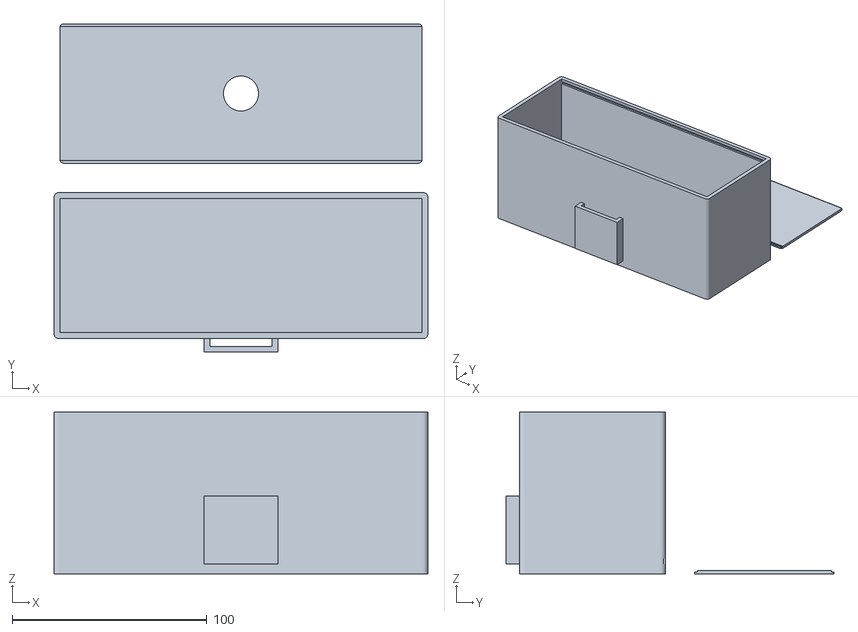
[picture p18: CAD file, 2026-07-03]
carcasa 3D/Carcasa Final.stl
192.0 x 168.6 x 83.0

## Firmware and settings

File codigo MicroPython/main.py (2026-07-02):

# ============================================================
#  DETECTOR DE CAÍDAS v22 — con WiFi + Telegram
#  MicroPython para Raspberry Pi Pico W (o ESP32)
# ============================================================

from machine import Pin, I2C
import machine
import network
import urequests   # Librería HTTP incluida en MicroPython
import time
import math
import struct

# ======================
# ZONA DE CONFIGURACIÓN  
# ======================
# --- Datos de la persona (aparecen en los mensajes de Telegram) ---
NOMBRE_PERSONA = "COLOCA EL NOBRE DEL FAMILIAR MAYOR"   # Nombre que podrán ver los familiares

WIFI_NOMBRE = "COLOCA AQUI EL NOMBRE DE TU WIFI" #Nombre de red SSID
WIFI_CLAVE = "COLOCA AQUI LA CLAVE DE TU WIFI"

# --- El bot de Telegram (ver instrucciones para configurar el bot) ---
TELEGRAM_TOKEN = "COLOCA AQUI EL TOKEN DE TU BOT"
TELEGRAM_CHAT_ID = "COLOCA AQUI EL ID DEL CHAT"

# --- Modo de prueba ---
MODO_PRUEBA = False # True: confirma la caida al detectar giro brusco. Uso solo para pruebas

# --- Umbrales del detector ---
UMBRAL_CAIDA_MIN     = 1.1   # Movimiento minimo en g
UMBRAL_GIRO_DPS      = 72    # Giro brusco en grados/segundo
UMBRAL_INCLINACION   = 50    # Postura anormal en grados

# --- Confirmación posterior (evita que un salto, sentarse o echarse de forma normal active la alarma) ---

TIEMPO_VERIFICACION   = 2.5   # segundos para revisar postura + inmovilidad tras el giro
UMBRAL_QUIETUD        = 0.70  # variación máxima de aceleración para considerar "inmóvil" (g)

# Porcentaje del TIEMPO_VERIFICACION que se descarta al principio (el "rebote" justo después del golpe) 
PORCENTAJE_ASENTAMIENTO = 0.20

TIEMPO_CANCELACION   = 5    # segundos para cancelar con 1 toque
TIEMPO_ALARMA_MAXIMO = 300   # segundos antes de apagarse sola (5 min)

# --- WiFi: cuántas veces intenta conectar antes de rendirse ---
INTENTOS_WIFI_INICIAL     = 50   # intentos al arrancar el dispositivo
INTENTOS_WIFI_RECONEXION  = 20   # intentos cuando se reconecta tras una caída de WiFi

# --- Para silenciar la alarma de emergencia ---
TOQUES_PARA_SILENCIAR = 2    # toques necesarios
VENTANA_TOQUES        = 2.0  # segundos en los que deben ocurrir

# --- Tiempos del pitido ---
PITIDO_ON  = 0.15   # más breve y rápido que antes -> suena más urgente
PITIDO_OFF = 0.15
PITIDO_ALERTA_DURACION = 0.15   # pitido corto al detectar, antes de la ventana de cancelación
PAUSA_ENTRE_GRUPOS = 0.70   # pausa entre cada "doble pitido" de emergencia (tipo sirena)                        

# --- Pitido durante los 5s de cancelación (TIEMPO_CANCELACION) ---
PITIDO_ON_CANCELACION  = 0.15   # duración de cada pitido durante la cancelación
PITIDO_OFF_CANCELACION = 0.15   # silencio entre cada pitido durante la cancelación

# --- Truco anti-apagado del power bank ---
INTERVALO_ANTIAPAGADO = 3    # segundos entre cada pulso anti-apagado
PULSO_ANTIAPAGADO     = 0.1  # duración del pulso (muy breve)

# =======================================
# INSTRUCCIONES PARA CONFIGURAR TELEGRAM
#
#  PASO 1 — Crear el bot:
#    a) Abre Telegram y busca "@BotFather"
#    b) Escribe /newbot
#    c) Ponle un nombre, ej: "Alerta Abuela María"
#    d) BotFather te dará un TOKEN como: 123456789:ABCdef...
#    e) Cópialo en TELEGRAM_TOKEN arriba
#
#  PASO 2 — Crear el grupo familiar:
#    a) Crea un grupo en Telegram con los familiares
#    b) Añade tu bot al grupo
#    c) Escríbele al bot desde el grupo: /start
#    d) Entra a este link en el navegador (cambia TOKEN por el tuyo): https://api.telegram.org/botTOKEN/getUpdates
#    e) Busca "chat":{"id": y copia ese número (empieza con -)
#    f) Pégalo en TELEGRAM_CHAT_ID arriba
# =======================================

MPU = 0x68  # Direccion I2C del MPU6050

# ===========================
# CONFIGURACIÓN DEL HARDWARE
# ===========================
def inicializar_hardware():
    global buzzer_pin, boton, i2c, wifi

    buzzer_pin = Pin(16, Pin.OUT)
    buzzer_pin.value(1)   # 1 = APAGADO de inmediato
    boton  = Pin(14, Pin.IN, Pin.PULL_UP)

    i2c = I2C(0, scl=Pin(5), sda=Pin(4), freq=400000)
    i2c.writeto_mem(MPU, 0x6B, b'\x00')   # Despierta el acelerómetro

    wifi = network.WLAN(network.STA_IF)
    wifi.active(True)

# ========================
# FUNCIONES DE BUZZER
# ========================

def buzzer_on(frecuencia=None):
    buzzer_pin.value(0)   # 0 = encendido (lógica invertida) 

def buzzer_off():
    buzzer_pin.value(1)   # 1 = apagado (lógica invertida)

# FUNCIÓN: CONECTAR AL WIFI

TIEMPO_ENTRE_REVISIONES_WIFI = 2   # segundos entre cada revisión de la conexión

def conectar_wifi():
    """
    Conecta al WiFi y espera hasta que haya conexión.
    Muestra un punto cada segundo mientras espera.
    Si no conecta en 20 segundos, continúa sin internet
    """
    wifi.connect(WIFI_NOMBRE, WIFI_CLAVE)

    print(f"Conectando a WiFi '{WIFI_NOMBRE}'", end="")
    intentos = 0
    while not wifi.isconnected() and intentos < INTENTOS_WIFI_INICIAL:
        print(".", end="")
        time.sleep(1)
        intentos += 1

    if wifi.isconnected():
        print(f"\n WiFi conectado - IP: {wifi.ifconfig()[0]}\n")
        return True
    else:
        print("\n No se pudo conectar al WiFi. Sin alertas Telegram.\n")
        return False

def verificar_wifi(avisar=True):
    """
    Revisa si el WiFi sigue conectado. Si se cayó, intenta reconectar
    de inmediato (rápido, sin esperar los 20 segundos completos) y
    muestra en consola si lo logró o no, igual que con las caídas.
    Devuelve True/False según el estado actual de la conexión.
    """
    if wifi.isconnected():
        return True

    print("\n>>> WiFi desconectado. Intentando reconectar... <<<")
    wifi.disconnect()
    wifi.connect(WIFI_NOMBRE, WIFI_CLAVE)

    intentos = 0
    while not wifi.isconnected() and intentos < INTENTOS_WIFI_RECONEXION:
        print(".", end="")
        time.sleep(1)
        intentos += 1

    if wifi.isconnected():
        print(f"\n>>> WiFi reconectado - IP: {wifi.ifconfig()[0]} <<<\n")
        if avisar:
            enviar_telegram(
                f"Dispositivo de {NOMBRE_PERSONA} reconectado al WiFi.\n"
                f"El monitoreo de Telegram esta activo de nuevo."
            )
        return True
    else:
        print("\n>>> Reconexión fallida. Se reintentará pronto. <<<\n")
        return False

# =======================================
# FUNCIÓN: ENVIAR MENSAJE A TELEGRAM
# =======================================

def enviar_telegram(mensaje, intentos=2):
    """
    Envía un mensaje al grupo de Telegram usando GET con URL.
 

    Reintenta una vez más si falla (con una pequeña pausa), porque
    justo después de reconectar el WiFi, el router ya da conexión.
    """
    for intento in range(1, intentos + 1):
        try:
            # Limpiamos caracteres especiales que rompen la URL
            msg = mensaje
            for orig, repl in [(" ", "%20"), ("\n", "%0A"), ("á","a"), ("é","e"),
                               ("í","i"), ("ó","o"), ("ú","u"), ("ñ","n"),
                               ("¡",""), ("¿",""), ("<b>",""), ("</b>","")]:
                msg = msg.replace(orig, repl)

            url = (f"https://api.telegram.org/bot{TELEGRAM_TOKEN}/sendMessage"
                   f"?chat_id={TELEGRAM_CHAT_ID}&text={msg}")

            respuesta = urequests.get(url, timeout=10)
            respuesta.close()
            print(f"  [Telegram] Enviado OK")
            return True
        except Exception as e:
            print(f"  [Telegram] Error (intento {intento}/{intentos}): {e}")
            if intento < intentos:
                time.sleep(1.5)   # le damos un respiro a la red antes de reintentar

    # Todos los intentos fallaron — el detector sigue funcionando igual
    return False

# FUNCIÓN: LEER EL ACELERÓMETRO MPU-6050

def leer_mpu6050():
    """
    Lectura del acelerómetro y giroscopio del MPU6050.
    
    Devuelve:
    -> aceleracion_total: magnitud de aceleración en g
    -> giro_total: magnitud del giro en grados/segundo
    -> roll: inclinación lateral
    -> pitch: inclinación frontal
    -> gx, gy, gz: giroscopio por eje
    """
    datos = i2c.readfrom_mem(MPU, 0x3B, 14)
    
    # Acelerómetro
    ax = struct.unpack(">h", datos[0:2])[0] / 16384.0
    ay = struct.unpack(">h", datos[2:4])[0] / 16384.0
    az = struct.unpack(">h", datos[4:6])[0] / 16384.0
    
    # Giroscopio
    gx = struct.unpack(">h", datos[8:10])[0] / 131.0
    gy = struct.unpack(">h", datos[10:12])[0] / 131.0
    gz = struct.unpack(">h", datos[12:14])[0] / 131.0
    
    # Magnitud total del acelerómetro
    aceleracion_total = math.sqrt(ax * ax + ay * ay + az * az)

    # Magnitud total del giroscopio
    giro_total = math.sqrt(gx * gx + gy * gy + gz * gz)
    
    # Inclinación aproximada usando acelerómetro
    roll = math.degrees(math.atan2(ay, az))
    pitch = math.degrees(math.atan2(-ax, math.sqrt(ay * ay + az * az)))
    
    return aceleracion_total, giro_total, roll, pitch, gx, gy, gz

# =========================================================
# FUNCIÓN: ESPERAR 1 SOLO TOQUE (para cancelar la alerta)
# =========================================================

def esperar_un_toque(segundos):
    """
    Espera hasta 'segundos' a que se presione el botón UNA VEZ.
    Devuelve True si se presionó, False si se acabó el tiempo.

    Se usa en la ventana de 15s porque la anciana está asustada
    y no puede recordar secuencias. Un toque basta para decir
    "estoy bien".
    """
    inicio        = time.time()
    boton_soltado = True

    while (time.time() - inicio) < segundos:
        presionado = (boton.value() == 0)   # Pull-up: 0 = presionado

        if presionado and boton_soltado:
            return True

        boton_soltado = not presionado
        time.sleep(0.02)

    return False

# FUNCIÓN: ESPERAR 1 TOQUE, PERO PITANDO FUERTE Y SEGUIDO MIENTRAS TANTO

def esperar_toque_con_pitido(segundos, pitido_on=PITIDO_ON_CANCELACION, pitido_off=PITIDO_OFF_CANCELACION):
    """
    Igual que esperar_un_toque(), pero además hace sonar el buzzer en
    pitidos repetidos durante toda la espera (no solo al principio),

    Devuelve True si se presionó el botón (y deja el buzzer apagado),
    False si se acabó el tiempo sin que nadie tocara.
    """
    inicio          = time.time()
    boton_soltado   = True
    pitido_prendido = False
    ultimo_cambio   = time.time()

    while (time.time() - inicio) < segundos:
        presionado = (boton.value() == 0)   # Pull-up: 0 = presionado

        if presionado and boton_soltado:
            buzzer_off()
            return True

        boton_soltado = not presionado

        # Alternamos encendido/apagado del buzzer sin bloquear la revisión del botón (revisamos cada pocos milisegundos)
        ahora = time.time()
        duracion_fase = pitido_on if pitido_prendido else pitido_off
        if (ahora - ultimo_cambio) >= duracion_fase:
            pitido_prendido = not pitido_prendido
            if pitido_prendido:
                buzzer_on()
            else:
                buzzer_off()
            ultimo_cambio = ahora

        time.sleep(0.01)

    buzzer_off()
    return False

def esperar_secuencia_toques(segundos_totales):
    """
    Busca TOQUES_PARA_SILENCIAR toques dentro de VENTANA_TOQUES segundos.
    Devuelve True si se completa la secuencia, False si no.

    Se usa en la alarma de emergencia para que no se apague
    por accidente. Solo alguien consciente puede hacer 4 toques
    rápidos. La anciana caída no podría hacerlo.
    """
    conteo              = 0
    tiempo_primer_toque = 0
    boton_soltado       = True
    inicio              = time.time()

    while (time.time() - inicio) < segundos_totales:
        presionado = (boton.value() == 0)

        if presionado and boton_soltado:
            ahora = time.time()

            if conteo == 0:
                # Primer toque: empezamos a contar la ventana
                conteo              = 1
                tiempo_primer_toque = ahora
                print(f"  Toque 1/{TOQUES_PARA_SILENCIAR}")

            elif (ahora - tiempo_primer_toque) <= VENTANA_TOQUES:
                # Toque dentro de la ventana: sumamos
                conteo += 1
                print(f"  Toque {conteo}/{TOQUES_PARA_SILENCIAR}")
                if conteo >= TOQUES_PARA_SILENCIAR:
                    return True   # ¡Secuencia completa!

            else:
                # La ventana expiró: reiniciamos desde este toque
                conteo              = 1
                tiempo_primer_toque = ahora
                print(f"  Toque 1/{TOQUES_PARA_SILENCIAR} (reiniciado)")

        boton_soltado = not presionado
        time.sleep(0.02)

    return False

# INICIO DEL PROGRAMA

def ejecutar_programa():
    """
    Contiene todo el programa: conexión WiFi, mensaje inicial y el bucle principal. Se ejecuta dentro de un bucle exterior 
    que atrapa si algo falla de forma grave y así el dispositivo nunca se queda apagado/muerto mientras tenga batería.
    """
    inicializar_hardware()   # prepara buzzer, botón, sensor MPU6050 y WiFi


    print(f"  DETECTOR DE CAIDAS v22")
    print(f"  Persona: {NOMBRE_PERSONA}")
    print(f"  1 toque       -> cancela alerta")
    print(f"  {TOQUES_PARA_SILENCIAR} toques en {VENTANA_TOQUES}s -> silencia emergencia")
    
    wifi_ok = conectar_wifi()   # Intentamos conectar al WiFi al arrancar

    if wifi_ok:
        # Mensaje de prueba para confirmar que Telegram funciona
        enviar_telegram(f"Dispositivo de {NOMBRE_PERSONA} conectado y listo.")

    ultima_revision_wifi = time.time()
    ultimo_pulso_antiapagado = time.time()


    # BUCLE PRINCIPAL
    while True:
        try:
            # --------------------------------------------------------
            # Revisamos el WiFi cada pocos segundos (no en cada vuelta del
            # bucle, para no atrasar la lectura de los sensores). Si se
            # cayó, intenta reconectar y avisa en consola si lo logró o no.
            # --------------------------------------------------------
            if (time.time() - ultima_revision_wifi) > TIEMPO_ENTRE_REVISIONES_WIFI:
                verificar_wifi()
                ultima_revision_wifi = time.time()

            # --------------------------------------------------------
            # Truco anti-apagado del power bank: cada cierto tiempo generamos 
            # un pequeño pulso de consumo extra para que el
            # power bank no piense que no hay nada conectado.
            # --------------------------------------------------------
            if (time.time() - ultimo_pulso_antiapagado) > INTERVALO_ANTIAPAGADO:
                buzzer_on()
                time.sleep(PULSO_ANTIAPAGADO)
                buzzer_off()
                ultimo_pulso_antiapagado = time.time()

            accel, giro, roll, pitch, gx, gy, gz = leer_mpu6050()

            print(
                "Aceleración:", round(accel, 2), "g",
                "| Giro total:", round(giro, 2), "°/s",
                "| Gx:", round(gx, 2),
                "| Gy:", round(gy, 2),
                "| Gz:", round(gz, 2),
                "| Roll:", round(roll, 2), "°",
                "| Pitch:", round(pitch, 2), "°"
            )

            # --------------------------------------------------------
            # PASO 1: ¿Hubo un evento decisivo de caída?
            # --------------------------------------------------------
            inclinacion = max(abs(roll), abs(pitch))
            evento_decisivo = (accel > UMBRAL_CAIDA_MIN and giro > UMBRAL_GIRO_DPS)

            if evento_decisivo:
                print("\n>>> Giro brusco detectado - verificando si es una caída real... <<<")
                print("Aceleración:", round(accel, 2), "g | Giro:", round(giro, 2), "°/s")

                if MODO_PRUEBA:
                    print(">>> MODO_PRUEBA activo: se confirma de una vez, sin revisar postura <<<\n")
                    posible_caida = True

                else:
                    # ----------------------------------------------------------------
                    # PASO 2: VERIFICACIÓN DE POSTURA + INMOVILIDAD
                    # ----------------------------------------------------------------
                    lecturas_verificacion = []
                    inicio_verif = time.time()
                    tiempo_asentamiento = TIEMPO_VERIFICACION * PORCENTAJE_ASENTAMIENTO   # descarta el rebote del golpe

                    while (time.time() - inicio_verif) < TIEMPO_VERIFICACION:
                        a_v, g_v, roll_v, pitch_v, _, _, _ = leer_mpu6050()
                        transcurrido = time.time() - inicio_verif

                        # Solo guardamos lecturas DESPUÉS del asentamiento
                        if transcurrido >= tiempo_asentamiento:
                            lecturas_verificacion.append(a_v)

                        etiqueta = "asentando" if transcurrido < tiempo_asentamiento else "midiendo quietud"
                        print(f"    [{etiqueta}] accel={round(a_v,2)}g  "
                              f"roll={round(roll_v,1)}°  pitch={round(pitch_v,1)}°")
                        time.sleep(0.1)

                    inclinacion_final = max(abs(roll_v), abs(pitch_v))
                    if len(lecturas_verificacion) >= 2:
                        variacion = max(lecturas_verificacion) - min(lecturas_verificacion)
                    else:
                        # Si TIEMPO_VERIFICACION es muy corto y no alcanzó a tomar lecturas tras el asentamiento confiable
                        variacion = 999
                    quieta = variacion < UMBRAL_QUIETUD
                    postura_anormal = inclinacion_final > UMBRAL_INCLINACION

                    print(f"  Inclinación final: {round(inclinacion_final,1)}° | "
                          f"Variación de accel: {round(variacion,2)}g | "
                          f"Quieta: {quieta} | Postura anormal: {postura_anormal}")

                    posible_caida = quieta and postura_anormal

                    if not posible_caida:
                        print(">>> Descartado: parece un movimiento brusco normal (salto, giro rápido, etc.) <<<\n")

            else:
                posible_caida = False

            if posible_caida:
                print("\n>>> ¡CAÍDA CONFIRMADA POR SECUENCIA DE SENSORES! <<<")
                print("Motivo: giro brusco + postura anormal + inmovilidad posterior")

                buzzer_on()
                time.sleep(PITIDO_ALERTA_DURACION)
                buzzer_off()   # pitido corto en vez de tono continuo

                # Enviamos PRIMER MENSAJE: posible caída, aún sin confirmar
                enviar_telegram(
                    f"POSIBLE CAIDA - {NOMBRE_PERSONA}\n"
                    f"Podria haberse caido. Esperando confirmacion...\n"
                    f"({TIEMPO_CANCELACION} segundos para cancelar)"
                )

                # ------------------------------------------------------------------
                # PASO 3: VENTANA DE CANCELACIÓN (TIEMPO_CANCELACION segundos)
                # ------------------------------------------------------------------
                cancelada          = False
                inicio_cancelacion = time.time()

                while (time.time() - inicio_cancelacion) < TIEMPO_CANCELACION:
                    restante = TIEMPO_CANCELACION - int(time.time() - inicio_cancelacion)
                    print(f"  Presiona 1 vez para cancelar: {restante}s")

                    if esperar_toque_con_pitido(2.0):
                        print("\n>>> ALERTA CANCELADA — Persona estable <<<\n")
                        buzzer_off()
                        cancelada = True

                        # Enviamos SEGUNDO MENSAJE: falsa alarma, tranquilos
                        enviar_telegram(
                            f"FALSA ALARMA - {NOMBRE_PERSONA}\n"
                            f"Cancelo la alerta ella misma. Esta bien."
                        )
                        time.sleep(1)
                        break

                # --------------------------------------------------------
                # PASO 4: EMERGENCIA CONFIRMADA
                # --------------------------------------------------------
                if not cancelada:
                    buzzer_off()
                    print("\n***** ¡EMERGENCIA CONFIRMADA! *****")
                    print(f"  Da {TOQUES_PARA_SILENCIAR} toques en {VENTANA_TOQUES}s para silenciar.")
                    print(f"  La alarma se apaga sola en {TIEMPO_ALARMA_MAXIMO}s.")

                    # Enviamos TERCER MENSAJE: emergencia real, necesita ayuda
                    enviar_telegram(
                        f"CAIDA CONFIRMADA - {NOMBRE_PERSONA}\n"
                        f"No respondio en {TIEMPO_CANCELACION} segundos.\n"
                        f"Vayan a ayudarla de inmediato.\n"
                        f"La alarma sonara hasta que alguien llegue."
                    )

                    inicio_alarma = time.time()
                    silenciada    = False

                    # --------------------------------------------------------
                    # Seguimiento del WiFi DENTRO de la emergencia (hasta 5 min)
                    # --------------------------------------------------------
                    wifi_conectado_antes = wifi.isconnected()
                    ultimo_intento_reconexion_alarma = time.time()

                    while (time.time() - inicio_alarma) < TIEMPO_ALARMA_MAXIMO:

                        wifi_conectado_ahora = wifi.isconnected()
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
